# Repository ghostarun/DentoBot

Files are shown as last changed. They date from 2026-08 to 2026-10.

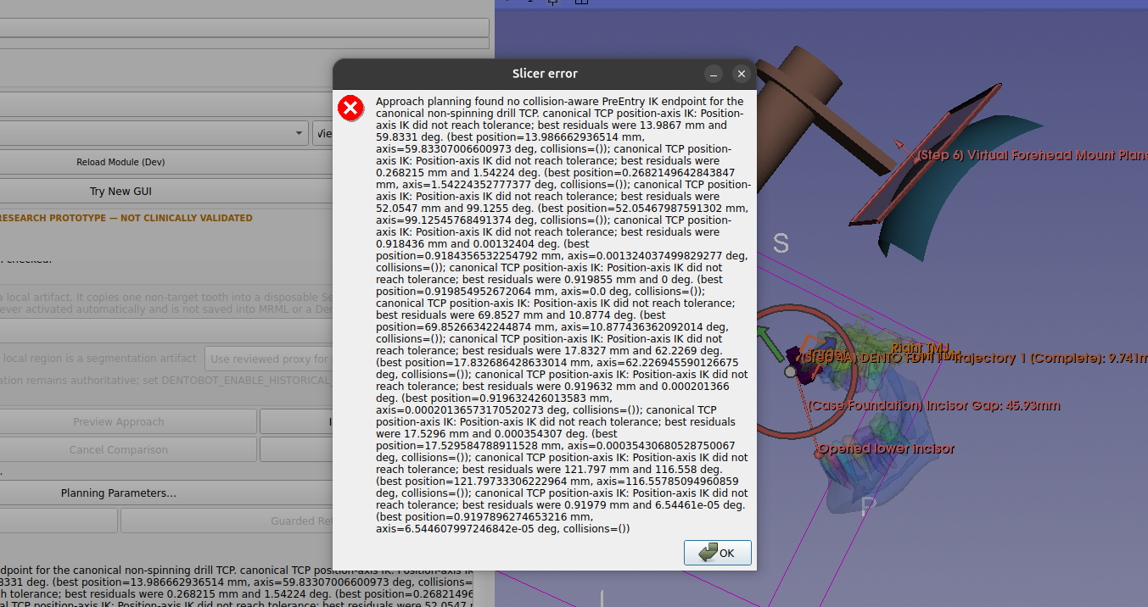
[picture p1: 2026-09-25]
Workspace/docs/diagnostics/evidence/fdi11-step6-2026-09-24/07-later-ik-error-repeat.png

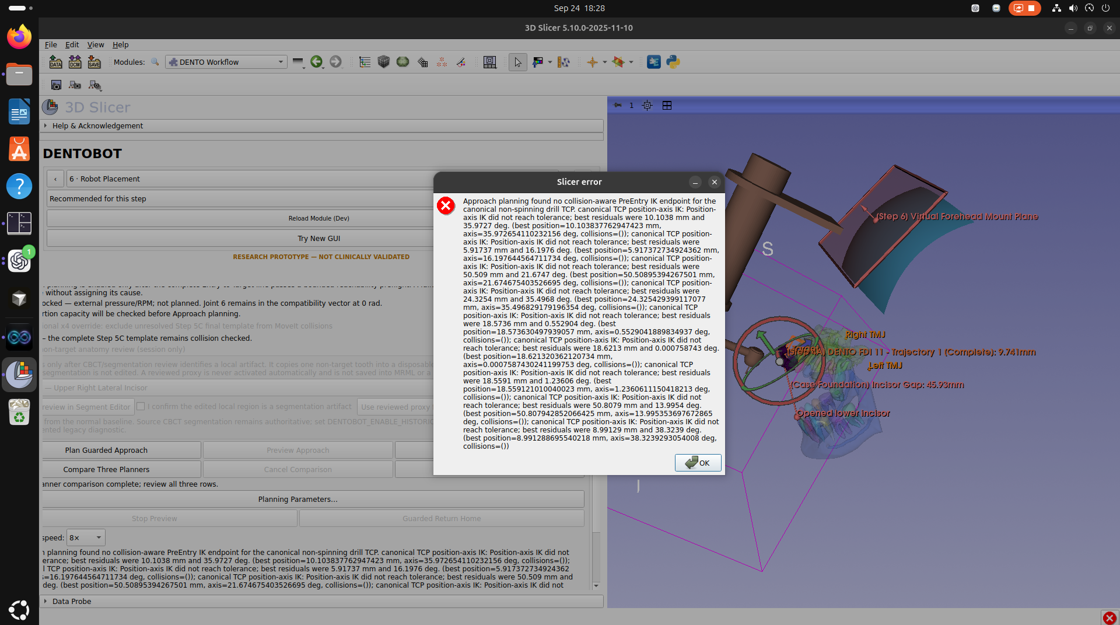
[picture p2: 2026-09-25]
Workspace/docs/diagnostics/evidence/fdi11-step6-2026-09-24/03-earlier-ik-error.png

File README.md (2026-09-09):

# DENTOBOT

DENTOBOT is an academic research prototype for a focused dental
image-guidance workflow built on 3D Slicer. It is not validated clinical
software and does not authorize drilling or patient treatment.

## Alternating development between machines

Use `main` as the shared development baseline and work on only one machine at
a time. Before switching devices, commit the intended source/documentation
changes and push the active branch. On the next device, inspect `git status`,
fetch origin, and use `git pull --ff-only` on that same branch before editing.
If Git reports local changes or divergent history, preserve that work and
reconcile it before continuing; do not reset or force-push to synchronize.
Uncommitted files and local-only commits do not travel between machines.

Keep `.dentobot.env`, `compose.override.yaml`, datasets, model caches, Conda
environments, and build/install trees local to each device. Record the active
branch, commit, outstanding work, and verification limits in the dated logbook
at handoff. Each machine retains its own CPU/CUDA and graphics configuration.

The Ubuntu NVIDIA and Windows WSLg/CUDA setup paths are integrated in `main`.
Each remains tied to its documented host profile and recorded verification;
installation on a new machine still ends with the profile's check-only gate.

## Supported runtime profiles

DENTOWorkflow uses the same MRML, planning, and geometry code on Windows and
Linux. Only the external-process and deployment adapters differ:

| Host profile | Slicer process | Inference process | Docker | SlicerROS2 |
|---|---|---|---|---|
| Windows 11 + WSLg (primary) | Linux Slicer 5.10 in `dentobot-slicerros2` through WSLg | Direct Linux Python in WSL (`cpu` or `cuda:0`) | Required | Included; Steps 0–6 simulation |
| Native Windows fallback | Native Windows Slicer | WSL2 Linux (`wsl.exe`) | Not required | Unavailable; Steps 0–5 only |
| Ubuntu (CPU) | Linux Slicer in the pinned SlicerROS2 container | Direct external Linux Python (`cpu`) | Required | Included |
| Ubuntu + NVIDIA | Same container | Direct external Linux Python (`cuda:0`) | Required + NVIDIA Container Toolkit | Included |

The inference stack is never installed into Slicer's embedded Python. Both
profiles launch the exact external Linux interpreter, exchange NIfTI plus
JSON in isolated run folders, and pass the device explicitly.

### Windows 11 + WSLg: primary full workflow and Step 6 simulation

Use this profile when Windows must run the same Linux SlicerROS2 simulation
stack as Ubuntu. It requires Windows 11 with WSLg, a WSL Ubuntu distribution,
and exactly one Docker daemon: Docker Engine inside that distribution by
default, or Docker Desktop with WSL integration as an alternative. Do not run
both daemon paths together. NVIDIA container support is required when using
`cuda:0`. WSLg is accepted for functional GUI checks, not rendering performance
acceptance. See [Workspace/docs/WINDOWS_SETUP.md](Workspace/docs/WINDOWS_SETUP.md)
for both host bootstraps. Lab users install immutable dated tags; `main` is not
a lab release.

```powershell
# Use the exact name printed by: wsl -l -v
$env:DENTOBOT_WSL_DISTRIBUTION = "Ubuntu"

# From a clone checked out at the intended lab tag or integration revision:
Workspace\scripts\install-lab-wsl.bat

# Cache TotalSegmentator tasks 298, 115, and 113. Safe to rerun.
Workspace\scripts\install-lab-model-cache.bat

# Launch Linux SlicerROS2 through WSLg.
Workspace\scripts\launch-lab-workflow.bat
```

The installer creates the WSL overlay and pins the SlicerROS2 dependency. Set
`DENTOBOT_GRAPHICS_MODE=wslg` in `~/dentobot/.dentobot.env`; select `cpu` with
the Python 3.12 CPU environment or `cuda:0` with the Python 3.10 cu130
environment. The launcher merges the tracked WSLg and CUDA Compose overlays,
builds the three required ROS packages in the bind-mounted workspace, checks
the selected inference device, and fails before GUI launch when prerequisites
are missing. See `Workspace/docs/SETUP.md` for GHCR authentication, environment
creation, first-install recovery, and exact verification commands.

### Legacy fallback: native Windows Slicer, Steps 0–5 only

This is a limited compatibility workaround. It deliberately hides Step 6,
does not load SlicerROS2, and must not be used when the full Windows
installation is intended. Native Windows Slicer plus native Windows ROS is
outside the current project scope.

Copy and edit the machine-local example, then launch native Windows Slicer:

```powershell
Copy-Item Workspace\.dentobot.windows.env.example .dentobot.windows.env
powershell -ExecutionPolicy Bypass -File `
  Workspace\scripts\launch-native-windows-steps0-5.ps1 -CheckOnly
powershell -ExecutionPolicy Bypass -File `
  Workspace\scripts\launch-native-windows-steps0-5.ps1
```

The Windows launcher validates Slicer, the named WSL distribution, the exact
Linux backend interpreter, the requested CPU/CUDA device, and a local Windows
run-record directory before opening DENTO Workflow. Docker Desktop is not
needed for Steps 0–5 segmentation, planning, template generation,
verification, or STL export. The launcher sets an explicit workflow profile
that removes Step 6 and disables its saved-checkpoint runtime restoration.

Current upstream SlicerROS2 1.2 compatibility targets Ubuntu 24.04, ROS 2
Jazzy, and source-built Slicer 5.10/5.12. A native Windows SlicerROS2 build is
not an upstream tested target. Robot/ROS-integrated Windows work uses the
primary Windows WSLg profile above. Native Windows Slicer remains the
Steps 0–5 fallback only.

Official references: [SlicerROS2 compatibility](https://slicer-ros2.readthedocs.io/en/devel/pages/compatibility.html),
[SlicerROS2 getting started](https://slicer-ros2.readthedocs.io/en/devel/pages/getting-started.html), and
[SlicerROS2 CI image](https://slicer-ros2.readthedocs.io/en/devel/pages/ci-docker-image.html).

## Ubuntu workspace orchestration

The repository lives at `ros2_ws/src/DentoBot` under an overlay root such as
`~/dentobot`. Tracked `Workspace/` owns the Ubuntu launcher, Compose
definition, helper scripts, active workspace notes, and top-level agent
instructions. The overlay preserves `scripts`, `docs`, `tools`,
`compose.yaml`, and `AGENTS.md` as relative symlinks. See
`Workspace/HOST_LAYOUT.md` for the overlay map.

Create the compatibility links safely in a new workspace with:

```bash
mkdir -p ~/dentobot/ros2_ws/src
git clone https://github.com/ghostarun/DentoBot.git ~/dentobot/ros2_ws/src/DentoBot
# Pin slicer_ros2_module to Workspace/LAB_RELEASE (required for Slicer launch)
git clone https://github.com/ghostarun/slicer_ros2_module.git \
  ~/dentobot/ros2_ws/src/slicer_ros2_module
git -C ~/dentobot/ros2_ws/src/slicer_ros2_module checkout \
  "$(awk -F= '/^SLICERROS2_SHA=/{print $2}' \
    ~/dentobot/ros2_ws/src/DentoBot/Workspace/LAB_RELEASE)"
bash ~/dentobot/ros2_ws/src/DentoBot/Workspace/bootstrap-workspace.bash
```

Copy `Workspace/.dentobot.env.example` to the workspace root as
`.dentobot.env` and edit only that untracked file for the local Conda
interpreter, device (`cpu` or `cuda:0`), and graphics render node. DENTO
Workflow receives those values from the launcher automatically; no machine
path needs to be remembered or saved in an MRB scene.

From the surrounding workspace, Git can be addressed without remembering the
nested checkout path:

```bash
scripts/git-dentobot.bash status --short --branch
```

### Ubuntu first-run checklist

1. Install Docker Engine. For NVIDIA hosts also install the NVIDIA Container
   Toolkit (`Workspace/scripts/install-host-nvidia-docker.bash` or equivalent)
   and reboot if the kernel module and userspace driver versions disagree.
2. Create the Conda `dentobot` environment from `Inference/` using either the
   Ubuntu CPU manifests or the Bridge C CUDA pins
   (`environment.yml` + `requirements/pytorch-cu130.txt` +
   `requirements/runtime-validated.txt`). Install CUDA torch **and**
   torchvision from the same `cu130` index (`torchvision==0.25.0+cu130`); a
   generic torchvision wheel breaks TotalSegmentator with
   `operator torchvision::nms does not exist`. Install packages into the env
   with `PYTHONNOUSERSITE=1` so nothing lands only under `~/.local` (user-site
   is not bind-mounted into the container).
3. Cache TotalSegmentator tasks **113**, **115**, and **298** under
   `data/model-cache/totalsegmentator`. Prefer calling
   `totalsegmentator.libs.download_pretrained_weights` for task IDs 115 and
   113; the CLI `-t` choices do not currently expose `teeth` /
   `craniofacial_structures` by name. Task 298 arrives with `total` /
   `total_fast`.
4. Build or pull the Compose image
   `dentobot/slicerros2:jazzy-moveit-sim-20260909` (see
   `Workspace/Dockerfile.slicerros2` / `Workspace/LAB_RELEASE`).
5. On NVIDIA hosts, the launcher automatically merges the tracked
   `Workspace/compose.cuda.yaml` when `DENTOBOT_BACKEND_DEVICE=cuda:0`.
   Reserve an untracked `compose.override.yaml` for machine-specific changes.
6. The launcher builds `dentobot_description`, `dentobot_moveit_config`, and
   `slicer_ros2_module` inside the container. A missing
   `slicer_ros2_module` install produces
   `package 'slicer_ros2_module' not found` at GUI launch.

```bash
cd ~/dentobot
./scripts/launch-dentoworkflow.bash --check-only
./scripts/launch-dentoworkflow.bash
```

Long-form workstation notes remain in `Workspace/docs/SETUP.md`.

## Ubuntu + NVIDIA (CUDA inference)

Verified on Ubuntu 22.04 with an AMD iGPU + NVIDIA RTX 4060 Laptop (driver
580.x, CUDA 13.0 wheels). Split responsibilities deliberately:

- **Slicer OpenGL:** Mesa DRM render node (AMD/Intel), set
  `DENTOBOT_RENDER_DEVICE` to the matching `/dev/dri/renderD*`.
- **Segmentation CUDA:** host Conda Python with `torch==2.10.0+cu130`,
  `DENTOBOT_BACKEND_DEVICE=cuda:0`, NVIDIA devices injected into the container
  through Container Toolkit and the tracked CUDA Compose overlay.

Example overlay `.dentobot.env` fragment:

```bash
DENTOBOT_BACKEND_PYTHON=/absolute/path/to/conda/envs/dentobot/bin/python
DENTOBOT_BACKEND_EXECUTION_MODE=local
DENTOBOT_BACKEND_DEVICE=cuda:0
DENTOBOT_RENDER_DEVICE=/dev/dri/renderD128   # Mesa node, not nvidia
```

Confirm before GUI launch:

```bash
nvidia-smi
docker run --rm --gpus all nvidia/cuda:12.6.0-base-ubuntu22.04 nvidia-smi
"$DENTOBOT_BACKEND_PYTHON" -m dentobot_inference health --json --require-device cuda:0
./scripts/launch-dentoworkflow.bash --check-only
```

Reject `llvmpipe` / `swrast` for interactive OpenGL acceptance unless software
rendering is deliberate. A driver/library version mismatch
(`NVML` vs loaded kernel module) requires reboot after cleaning duplicate
driver packages.

## ROS 2 robot description

The tracked `dentobot_description` package is exposed to colcon through the
workspace bootstrap's `ros2_ws/src/dentobot_description` relative symlink.
Build and run the simulation-only neutral description inside the Jazzy
container:

```bash
docker exec dentobot-slicerros2 bash -lc \
  'source /opt/ros/jazzy/setup.bash &&
   cd /workspace/ros2_ws &&
   colcon build --symlink-install --packages-select dentobot_description'

docker exec -it dentobot-slicerros2 bash -lc \
  'source /opt/ros/jazzy/setup.bash &&
   source /workspace/ros2_ws/install/setup.bash &&
   ros2 launch dentobot_description description.launch.py use_rviz:=false'
```

The launch publishes neutral joint states and TF for inspection only. It has
no controller, command topic, hardware plugin, or motion path. See
`dentobot_description/README.md` for provenance and unresolved calibration,
collision, frame, and physical-verification work.

DENTOWorkflow also exposes **6 · Robot Placement** for scene-only
placement. It loads the same tracked URDF/STLs into an MRML transform hierarchy,
allows manual joint changes, and provides an editable mount plane with explicit
snap plus local button/keyboard nudges. This is not a live ROS/SlicerROS2 bridge:
it reads no robot state, sends no command, and does not establish head-mount
registration, a calibrated TCP, collision safety, or hardware readiness.

For the current disposable workspace check, Step 6 can load local aligned
BodyParts3D skull/maxilla/mandible meshes, collect approximate left/right TMJ
and upper/lower central-incisor landmarks, and rotate the mandible about the
TMJ axis to an approximately 40 mm final incisor gap. The robot base can then
be dragged/snapped to a provisional forehead plane, fine-tuned by buttons or
opt-in keyboard controls, and articulated with the six manual joint controls.
See `Workspace/docs/SETUP.md` for asset checksums and the exact trial sequence.
This is generic design visualization only, not clinical jaw simulation,
registration, collision validation, or robot control.

## Ubuntu interactive rendering

A visible Slicer window does not prove hardware acceleration. On Ubuntu,
containerized Slicer needs a working host GPU driver, a compatible userspace
OpenGL driver in the image, and explicit access to the intended DRM render
node.

Inspect the host first:

```bash
lspci -nnk | grep -A4 -Ei 'vga|3d|display'
ls -l /dev/dri
readlink -f /sys/class/drm/renderD128/device/driver
readlink -f /sys/class/drm/renderD129/device/driver
```

For Mesa-backed Intel and AMD graphics, map the actual non-modesetting render
node into the service (Compose already takes `DENTOBOT_RENDER_DEVICE`):

```yaml
services:
  slicerros2:
    devices:
      - /dev/dri/renderD128:/dev/dri/renderD128
```

The node number may differ on multi-GPU systems. Non-root container users also
need the matching host render-group GID. AMD requires a compatible Mesa
`radeonsi` driver. Proprietary NVIDIA CUDA for the *inference* process uses
NVIDIA Container Toolkit and `Workspace/compose.cuda.yaml`; do not copy the
Intel/AMD DRM recipe blindly as a substitute for `/dev/nvidia*`.

Slicer 5.10 may lower the entire Linux process priority when initializing its
background threads. Preserve interactive priority with:

```yaml
services:
  slicerros2:
    environment:
      SLICER_BACKGROUND_THREAD_PRIORITY: "0"
```

Save and close Slicer before recreating a container. Then verify both device
access and renderer identity; reject `llvmpipe` or `swrast` unless software
rendering is deliberately requested.

### Verified workstation notes

- **IITM CPU/Intel profile:** Intel Arrow Lake-S (`i915`),
  `/dev/dri/renderD128`, Mesa Intel OpenGL 4.6, Slicer nice 0,
  `DENTOBOT_BACKEND_DEVICE=cpu`. Full procedure: `Workspace/docs/SETUP.md`.
- **NVIDIA dual-GPU profile (2026-09-07):** Ubuntu 22.04, AMD Mesa render node
  for Slicer + NVIDIA RTX 4060 for `cuda:0` inference; launcher
  `--check-only` passed with CUDA health inside the container. See logbook
  `2026-09-07` and task `PLAT-U-05`.

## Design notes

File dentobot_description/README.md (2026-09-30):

# DENTOBOT ROS 2 description

This package is the first simulation-only integration of the supplied CAD
export. It publishes the URDF through `robot_state_publisher` and supplies
neutral, manual, and Slicer joint-state modes so the complete tree can be
inspected and articulated without a controller or robot connection.

## Source and normalization

The source bundle was received under the workspace-local
`data/ROS/assembly` directory on 2026-08-14. Its unmodified URDF SHA-256 is
`e04d644a85eaeb518507cbe991e2007e1f0194c7cc4b834fc608d9d6b1beda45`.
The seven copied binary STL checksums are enforced by the package test.

The initial integration made three URDF normalizations:

- the robot name changed from the generic `assembly` to `dentobot`;
- relative mesh paths changed to
  `package://dentobot_description/meshes/...`;
- a massless `base_link` and fixed joint were placed above `link-1`
  because KDL does not retain inertia on a URDF root link.

On 2026-08-14 the developer selected a photographed design pose as the new
draft zero configuration. The old manual arm values absorbed into the URDF
joint origins are J1 `25.38 deg`, J2 `0 mm`, J3 `62.46 deg`, J4 `0 mm`, and J5
`1.08 deg`; the finite revolute limits were shifted by the same offsets so
their original 360-degree spans remain available around the new zero. The
fixed spindle-housing-to-burr transform preserves the photographed tool
assembly pose. The fixed root rotates link-1 by -90 degrees about X, placing
its thin Y-normal mounting face on the RViz XY plane with the articulated chain
above the grid. J4's axis is negated while retaining its positive `0–75 mm`
control range, so increasing J4 now moves primarily in negative `base_link` X.

On 2026-09-01 J2 was normalized so its mechanically extended/home end is
`0 mm`. The former description used that same physical pose at `80 mm`.
The tracked URDF moves the J2 joint origin to the former `q=0.08 m` pose and
reverses its axis, so physical geometry is preserved by
`q_new = 0.08 m - q_old`. DENTOWorkflow applies this exact conversion only to
packages carrying the fingerprint of the tracked former URDF; saved Task Home
runtime evidence and workspace samples are then required to be regenerated.
The J1/J3/J5 photographed-pose offsets above remain absorbed into their URDF
origins, so their configured default Home values remain displayed as zero.

The same simulation-profile revision declares J5 continuous. The former
finite interval `-1.08–358.92 deg` covered one full revolution but forced a
pose just below zero to be represented as an almost-complete positive turn.
MoveIt and DENTOWorkflow now use the shortest representation relative to the
accepted start state for J5. Pneumatic turbine rotation is outside the
positioning model; the spindle housing and burr remain in the URDF as rigid
geometry.

The received source URDF remains unchanged under `data/ROS/assembly`. Mesh
bytes, link frames/geometries, masses, inertias, and the other joint axes are
unchanged in the tracked description.

## Build and inspect

From the DENTOBOT Jazzy container workspace:

```bash
source /opt/ros/jazzy/setup.bash
cd /workspace/ros2_ws
colcon build --symlink-install --packages-select dentobot_description
source install/setup.bash
ros2 launch dentobot_description description.launch.py
```

For a headless transport/TF check, omit RViz:

```bash
ros2 launch dentobot_description description.launch.py use_rviz:=false
```

## Manual joint articulation

From an Ubuntu graphical desktop terminal, use the workspace launcher:

```bash
cd /home/light-tarun/dentobot
./scripts/launch-dentobot-manual-rviz.bash
```

The launcher verifies the reusable container, rebuilds only this small
description package, refuses a duplicate description launch, grants temporary
X11 access, and opens RViz beside the package-owned manual slider window.

The five controls follow URDF order. Revolute values are displayed in degrees;
prismatic values are displayed in millimetres. Published
`sensor_msgs/msg/JointState` positions remain in ROS SI units (radians and
metres):

| Joint | Type | Manual display range |
| --- | --- | --- |
| `link-1_Revolute-1` | revolute | -25.38–334.62 deg |
| `link-2_Slider-2` | prismatic | 0 mm extended/home–80 mm retracted |
| `link-3_Revolute-3` | revolute | -62.46–297.54 deg |
| `link-4_Slider-4` | prismatic | 0–75 mm |
| `link-5_Revolute-5` | continuous | -180–180 deg display window |

All five displayed values start at zero. **Reset all joints to zero** restores
the photographed pose, not the original CAD-export pose.

The direct ROS equivalent is:

```bash
ros2 launch dentobot_description manual.launch.py
```

### Draft 5 mm link-box clearance

Manual mode computes a base-frame axis-aligned bounding box (AABB) around each
transformed collision mesh. It compares every non-adjacent link pair and warns
when the Euclidean distance between their boxes is below 5 mm. Direct
parent-child pairs are ignored because connected joint geometry is expected to
touch or overlap. The manual window lists the closest warning pairs and shows
the current `burr` link origin in `base_link` millimetres. RViz subscribes to
`/dentobot/coarse_self_collision_boxes`; green outlines are clear and red
outlines participate in a warning.

This is intentionally conservative draft logic. Rotated axis-aligned boxes can
overlap even when the actual triangles do not, and the current collision meshes
are the unreduced visual STLs. At neutral, the draft checker reports
`link-3`/`link-5` and `link-3`/`pneumatic_spindle-Copy` AABB overlap. Do not
interpret those warnings as confirmed physical collision, and do not interpret
a clear result as continuous-path or patient/head clearance. The `burr` origin
is a CAD link origin, not a calibrated tool centre point.

The default can be made more conservative for an experiment, for example:

```bash
ros2 launch dentobot_description manual.launch.py coarse_clearance_mm:=10.0
```

`description.launch.py` also accepts `joint_state_mode:=neutral` (the default),
`joint_state_mode:=manual`, `joint_state_mode:=slicer`, or
`joint_state_mode:=external`. Slicer mode starts
`dentobot_slicer_joint_state_publisher`, which republishes Motion Control
slider commands from `dentobot/slicer_joint_positions` as `/joint_states`.
External mode starts no joint-state source and exists for bounded TF tests or a
future simulator. Do not run more than one joint-state publisher for the model.

Package-owned publishers write `sensor_msgs/msg/JointState` for visualization.
The Slicer path also listens to `std_msgs/msg/Float64MultiArray` commands. None
of these interfaces expose controllers, transmissions, `ros2_control`, a
hardware plugin, or any robot motion path.

## Evidence boundary and open engineering work

Passing the package tests or displaying the model establishes only static and
synthetic description integrity. Before this model can support kinematics,
collision planning, calibration, or hardware integration, the team must verify:

- physical joint zero definitions, positive directions, usable ranges,
  velocity limits, effort limits, and units;
- link/joint naming and the intended `base_link`, end-effector, spindle, TCP,
  bur-tip, and docking frames;
- masses, centers of mass, and inertia tensors against the physical assembly;
- visual mesh alignment and scale against measured dimensions;
- simplified, conservative collision geometry instead of reusing every visual
  mesh verbatim;
- self-collision pairs, transmissions/actuators, controller interfaces, and
the robot-control/safety boundary;
- the explicit transform chain from Slicer RAS through the physical docking
  and robot frames.

No powered motion, drilling, patient use, or safety claim is authorized by
this package.

## Step 6 planning frame

MoveIt group `dentobot_arm` plans exactly J1–J5 to the fixed
`dentobot_drill_tcp` frame. The TCP keeps its existing burr-tip reference
transform and physical +Z drilling axis. The spindle housing, burr, and older
`dentobot_tool_tcp` and `dentobot_drill_tip_provisional` frames remain in the
description at fixed physical transforms for visualization and collision
checking. Task Home, IK, workspace samples, trajectories, phase-guard
commands, and previews use exactly five SI joint values.

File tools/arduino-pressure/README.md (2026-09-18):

# Arduino pressure monitor

Host sensing bench for the DENTOBOT pneumatic pressure setup: live serial
plot, stage cues, CSV recording, and post-run inspection.

Tracked path: `tools/arduino-pressure/` inside the DentoBot git checkout.
The Ubuntu overlay exposes it as `~/dentobot/tools/arduino-pressure` via
the same symlink pattern as `docs/` and `scripts/`.

Sensing only. It does not command a robot, authorize drilling, or implement
a safety stop. Do not install these packages into Slicer, Conda `dentobot`,
or the SlicerROS2 container.

## Layout

```text
tools/arduino-pressure/
  pressure_monitor.py       live GUI
  pressure_analysis.py      post-processing GUI / --no-gui
  pressure_config.py        filter / sample-rate panel
  pressure_filter.py
  pressure_signal.py
  pressure_plot.py
  pressure_annotate.py
  pressure_cli.py           --port / --wifi / --list-ports
  pressure_transport.py     serial vs WiFi TCP link
  pressure_bridge.py        USB→TCP when campus WiFi is LDAP/enterprise
  firmware/pressure_monitor/pressure_monitor.ino   Arduino sketch (firmware)
  firmware/pressure_monitor/arduino_secrets.h.example
  requirements.txt
  pressure_runs/            local CSVs (gitignored except .gitkeep)
```

## Setup (Ubuntu)

```bash
sudo apt update
sudo apt install python3 python3-venv python3-pip libxcb-cursor0 libxcb-xinerama0
cd tools/arduino-pressure
python3 -m venv .venv
source .venv/bin/activate
python -m pip install --upgrade pip
python -m pip install -r requirements.txt
sudo usermod -aG dialout "$USER"   # then log out and back in
```

On this workstation the existing interpreter is
`/home/light-tarun/pressure-env/bin/python`.

## Setup (Windows)

1. Install Python 3.10+ with **Add python.exe to PATH**.
2. In this folder:

```bat
python -m venv .venv
.venv\Scripts\activate
python -m pip install --upgrade pip
python -m pip install -r requirements.txt
```

## Firmware (Arduino sketch)

In Arduino IDE 2.x this file is a **sketch** (not a “script”):
`firmware/pressure_monitor/pressure_monitor.ino`. Target board: **Arduino UNO
R4 WiFi** (plain UNO has no WiFi).

1. Copy `firmware/pressure_monitor/arduino_secrets.h.example` to
   `arduino_secrets.h` in the same folder.
2. **IITM `iitmwifi` (802.1X PEAP / LDAP):** the board **cannot** join the same
   network your laptop uses for campus login. Set `PRESSURE_WIFI_MODE` to **`2`**
   so the Arduino **hosts** a small WPA2 access point (`AP_SSID` / `AP_PASS`).
   On the PC, connect WiFi to that AP (you can keep **Ethernet** on `iitmwifi`
   for internet). Then:
   `python pressure_monitor.py --wifi --wifi-host 192.168.4.1` (confirm IP on
   Serial Monitor once after flash).
3. **Other WPA2-PSK WiFi (phone hotspot, lab router):** `PRESSURE_WIFI_MODE`
   **`1`**, set `SECRET_SSID` / `SECRET_PASS`, flash, read `# WIFI IP …` on
   Serial Monitor at 460800 baud.
4. **WiFi off:** `PRESSURE_WIFI_MODE` **`0`** — USB only, or USB +
   `pressure_bridge.py` if the PC is on campus WiFi and you want TCP.
5. USB line format: `seq,micros,raw_adc`. Host command: `RATE <hz>` (200–1500).
   The same lines work over **TCP** (board WiFi or host bridge).

### Campus network: USB + bridge (recommended)

Your laptop joins campus WiFi with LDAP as usual. The Arduino stays on USB.

```bash
# Terminal 1 — on the laptop that owns the USB cable
python pressure_bridge.py --port /dev/ttyACM0 --listen 0.0.0.0:8765

# Terminal 2 — same laptop or another PC on the same campus LAN
python pressure_monitor.py --wifi --wifi-host <laptop-ip>
```

Use the laptop’s campus IP (`ip a` / `hostname -I`). Firewall rules on the
laptop must allow inbound TCP 8765 from your bench PC if you split terminals
across machines. Same-machine use: `--wifi-host 127.0.0.1`.

Ask campus IT for a **device PSK SSID** only if you need the board on WiFi
without a bridge; LDAP credentials still cannot be stored in the sketch.

## Run

`pressure_monitor.py` sets **`USE_WIFI_BY_DEFAULT = True`** and
**`DEFAULT_WIFI_HOST = 192.168.4.1`** at the top of the file (same on Linux and
Windows). With the PC WiFi joined to the board AP, run with **no arguments**:

```bash
python pressure_monitor.py
```

Set `USE_WIFI_BY_DEFAULT = False` there to fall back to USB serial.

**Linux**

```bash
python pressure_monitor.py --list-ports
python pressure_monitor.py --port /dev/ttyACM0   # USB if WiFi default off
python pressure_monitor.py --wifi --wifi-host 192.168.4.1
./run_monitor.sh
./run_monitor_wifi.sh
```

**Windows** (venv activated or `run_monitor.bat`)

```bat
python pressure_monitor.py
python pressure_monitor.py --list-ports
python pressure_monitor.py --port COM5
python pressure_monitor.py --wifi --wifi-host 192.168.4.1
run_monitor.bat
run_monitor_wifi.bat
set PRESSURE_WIFI_HOST=192.168.4.1
```

Allow **Python** through Windows Firewall if the GUI connects but gets no data.
`pressure_analysis.py` / `pressure_analysis.py --no-gui` work the same on both OSes.

Helpers: `run_monitor.sh` / `run_monitor.bat`, `run_monitor_wifi.sh` /
`run_monitor_wifi.bat`, and the analysis equivalents.

Recordings land in `pressure_runs/run_<timestamp>/`. Those folders are not
committed.

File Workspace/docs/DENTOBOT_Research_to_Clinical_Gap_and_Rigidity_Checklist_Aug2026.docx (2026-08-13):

DENTOBOT
Research-to-Clinical Gap Closure & Engineering Rigidity Checklist

Fast-track PoC decision document | IITM Dental Drilling Robot | August 2026

Purpose: convert the current software/geometry progress into a finite set of research questions, acceptance checks, and parallel project lanes. This is not a product-grade specification. It is a PoC closure document: answer enough of each question to make the TRL-4 prototype defensible, measurable, and ready to connect to registration and robotics.

# How to use this document

Use Section 1 with the dental/clinical team. Use Section 2 as the engineering rigidity checklist before calling a subsystem 'done enough'. Use Sections 3-5 to prevent DENTOBOT imaging/template work from hiding the tooth-mounted robot, registration, sensing, and robot-execution lanes.

Decision rule: every requirement should eventually become one of three things - a numeric acceptance threshold, a bounded qualitative acceptance test, or an explicitly deferred question with a reason.

# 1. Research → Clinical Requirement Closure Questions

## 1.1 Procedure and clinical use-case boundary

☐ What exact portion of root-canal treatment is this PoC intended to automate: access trajectory planning, access cavity drilling, chamber entry, or a narrower bounded drilling task?

☐ What is explicitly outside the autonomous scope for TRL-4?

☐ What is the clinician expected to approve before robot motion begins?

☐ What events require the clinician to stop, re-plan, re-register, or abandon autonomous execution?

☐ What is the expected patient/phantom positioning and what motion is permitted during the procedure?

☐ What is the intended failure-safe state if software, registration, sensing, or robot motion becomes uncertain?

## 1.2 Anatomy, segmentation and imaging

☐ Which anatomical structures must be segmented reliably for planning: whole tooth, crown, roots, pulp chamber/canals, neighboring teeth, bone, gingiva surrogate?

☐ What segmentation errors materially affect trajectory or template seating, and which errors are visually tolerable but clinically irrelevant?

☐ What is the minimum CBCT resolution/FOV/quality assumed by the PoC?

☐ How will metal artifacts, restorations, crowns, missing teeth, partial scans, and noisy boundaries be handled or excluded?

☐ What constitutes sufficient human review of the AI segmentation before planning?

☐ Do corrected masks require quantitative recomputation before downstream use, or is explicit provenance enough for PoC?

## 1.3 Entry, target and trajectory semantics

☐ What anatomical definition is used for Entry?

☐ What anatomical definition is used for Target/end point?

☐ What structures define a hard no-go region?

☐ What minimum remaining dentin/enamel safety margin is required around the planned path?

☐ What maximum angular and translational planning error is acceptable for the PoC?

☐ Should the trajectory be straight-line only for the PoC, and what drill/bur diameter/depth assumptions constrain it?

☐ What does the dentist need to see in oblique MPR to approve or correct a trajectory?

☐ What is the acceptance criterion for assisted/automatic trajectory suggestions versus manually corrected trajectories?

## 1.4 Tooth-supported template / shell

☐ Which surfaces are intended to provide support and retention: occlusal, buccal, lingual/palatal, proximal, or a controlled combination?

☐ What surfaces must be excluded because of gingiva/soft tissue, poor segmentation, restoration, or access difficulty?

☐ What insertion direction should the guide use, and can one direction serve all selected support teeth?

☐ How much undercut engagement is useful for retention and how much prevents seating/removal?

☐ What clearance should exist between tooth surface and printed shell for the chosen printer/material/process?

☐ What minimum wall thickness is needed to avoid clinically meaningful flexure during docking/drilling?

☐ What crown coverage is required for stable seating, and should coverage be geometry-driven rather than a fixed percentage?

☐ How many support teeth are required for the intended target and load case?

☐ What visual/tactile evidence makes the dentist accept or reject guide seating?

☐ How many repeated insert/remove cycles should preserve repeatable seating for the PoC?

☐ What is the acceptable rocking/gap at full seating?

☐ What gingival/cervical margin rule is acceptable for the PoC?

☐ What is the manufacturing/export validation required before a shell is considered testable?

## 1.5 Sleeve, channel and drilling interface

☐ What is the actual bur/drill outer diameter and what radial clearance is required?

☐ Is a physical sleeve required, or is the template primarily a robot docking reference?

☐ What sleeve/channel height is sufficient to constrain the tool without causing access or collision problems?

☐ What maximum axis misalignment between planned trajectory and fabricated channel is acceptable?

☐ What drill-depth stop or software depth reference is used?

☐ How is heat/debris/irrigation access affected by the guide?

☐ Does the guide need to resist direct drill reaction loads, robot docking loads, or both?

## 1.6 Registration and coordinate-chain requirements

☐ What is the authoritative patient/tooth coordinate frame?

☐ Where is the template coordinate frame physically realized?

☐ How is the robot base/end-effector frame registered to the template/tooth frame?

☐ Which transform chain is used to convert planned RAS trajectory coordinates into robot motion coordinates?

☐ Which transforms are measured once, which are calibrated, and which must be re-estimated after every mounting?

☐ What event invalidates registration: patient movement, guide removal, robot redocking, tool change, template deformation?

☐ What target registration error (TRE) at the tooth/drilling target is acceptable?

☐ How will registration error be measured independently from robot positioning error?

☐ Can the robot be removed and re-docked while preserving registration within the PoC tolerance?

## 1.7 Safety and clinical control

☐ What is the maximum allowed drilling depth and how is it independently limited?

☐ What hard geometric constraints prevent motion outside the approved corridor?

☐ What sensor/feedback condition should trigger immediate stop?

☐ What latency is acceptable between detected abnormal condition and drill stop?

☐ What happens if registration confidence degrades after approval?

☐ What physical emergency stop / software stop / clinician override is required for the prototype?

☐ What states require a fresh confirmation rather than continuing automatically?

# 2. Engineering Rigidity Checklist - 'Done Enough' Gates

This section is deliberately stricter than 'it worked once'. A PoC does not need product-grade robustness, but every critical assumption should survive a repeatable bounded test.

## 2.1 Data and geometry integrity

☐ Same CBCT produces the same physical geometry after save/reopen.

☐ Voxel spacing, origin, orientation/affine, and transforms are preserved across every external-process boundary.

☐ Segmentation aligns with source CBCT after inference/import and after MRB reopen.

☐ No logic relies on editable MRML node names for identity.

☐ Wrong-role nodes (e.g., Step 4A ROI used as Step 5B ROI) are rejected.

☐ Derived outputs identify their authoritative parents and Current/Stale state.

## 2.2 Segmentation / review robustness

☐ Representative CBCT loads and segmentation completes on the intended development runtime.

☐ Failure paths for missing model/dependency/device produce actionable errors rather than corrupted scene state.

☐ Human correction invalidates/relabels baseline metrics appropriately.

☐ Reviewed state survives scene save/reopen.

☐ Planning cannot silently proceed on the wrong segmentation/source pair.

## 2.3 Trajectory planning robustness

☐ Entry/Target invariant remains exactly 0-2 points; >2 cannot occur.

☐ Trajectory length/direction are calculated in world millimetres.

☐ Oblique MPR remains trajectory-aligned during correction and selection changes.

☐ Multiple trajectories remain correctly associated with their target teeth.

☐ Scene reopen restores target, trajectory, bounds, highlights and associations.

☐ Editing/deleting a trajectory cannot silently leave valid-looking but mismatched descendants.

## 2.4 Template geometry robustness

☐ Support selection produces one deterministic owned support-anatomy model.

☐ Automatic visible/crown support boundary is connected and editable.

☐ Insertion direction is explicit and persisted.

☐ Undercut handling does not produce a guide that cannot be inserted on representative anatomy.

☐ Clearance and wall thickness are explicit parameters with recorded values.

☐ Shell is watertight/manifold before export.

☐ Shell contains no obvious disconnected islands, self-intersections or unintended internal fragments.

☐ Trajectory/sleeve/docking geometry remains correctly aligned after shell regeneration.

☐ Finalized shell remains distinct from raw source shell and stale finalizations cannot export.

☐ STL reopens with expected scale, orientation and topology.

## 2.5 Physical template checks

☐ Print at least one representative guide with recorded material/process settings.

☐ Guide reaches intended terminal seating without excessive force.

☐ No visible rocking under light manual load.

☐ Repeated seating produces similar final pose.

☐ Guide can be removed without fracture or unacceptable locking.

☐ Shell does not visibly flex under expected docking/drilling load.

☐ Sleeve/docking feature remains rigid relative to tooth-supported body.

☐ Measure physical-versus-planned critical dimensions after printing.

## 2.6 Registration / metrology rigidity

☐ Every transform in the chain is explicitly named and directionally defined.

☐ Calibration and registration are independently repeatable.

☐ Registration error is measured at/near the drilling target, not only at fiducials.

☐ Repeat registration N times and report mean, standard deviation and worst case.

☐ Remove/reseat the template and quantify pose repeatability.

☐ Redock the robot and quantify docking repeatability.

☐ Separate imaging/segmentation, template seating, registration, robot kinematic and tool calibration error contributions where practical.

☐ Define a total allowable error budget before drilling tests.

## 2.7 Robot execution rigidity

☐ Robot can move to a planned pose in a safe phantom workspace.

☐ Tool center point and drill axis are calibrated.

☐ Commanded versus measured pose error is quantified.

☐ Software limits constrain motion to the approved workspace/corridor.

☐ Emergency stop and controlled stop are tested before powered drilling.

☐ Loss of communication or invalid state produces a safe stop.

☐ Dry-run trajectory execution is repeatable before spinning the drill.

☐ Depth-limited drilling into a non-clinical test material precedes tooth/phantom drilling.

## 2.8 Evidence discipline

☐ Every 'works' claim states whether evidence is static, synthetic, developer-live, representative anatomy, printed phantom, or clinical expert acceptance.

☐ Current default dimensions are labelled research defaults unless justified.

☐ Known limitations are recorded instead of hidden by UI automation.

☐ A reproducible test case exists for each critical pipeline stage.

☐ One end-to-end acceptance script/checklist can be run before weekly demonstrations.

# 3. Project Lanes - Keep All of These Alive

Lane | Immediate purpose | Next concrete milestone
A. DENTOBOT imaging/planning | Reliable CBCT -> reviewed anatomy -> approved trajectory | Close representative trajectory + template V0 acceptance; freeze PoC boundary
B. Template / physical interface | Convert anatomy/trajectory into a repeatably seatable reference body | Print, seat, undercut-check, measure repeatability, integrate docking geometry
C. Registration | Establish the patient/template -> robot transform chain | Define frames + registration method; build phantom registration experiment and TRE metric
D. Head-mounted / primary robot | Develop robot capable of executing the approved drill axis | Architecture/DOF/workspace/safety requirements -> first kinematic/mechanical prototype
E. Tooth-mounted robot | Explore compact robot mounted directly to dental reference | Define mechanism architecture, load path, actuation and disposable docking concept
F. Tool / aerotor integration | Make the drill a calibrated controllable end effector | Tool-axis/TCP calibration, depth control, on/off interface, load/thermal constraints
G. Sensing & stop logic | Detect abnormal drilling/material transitions | Pressure/acoustic experiment -> features -> threshold/feedback feasibility
H. Verification / metrology | Quantify total system accuracy and repeatability | Create error budget and bench measurement protocol
I. IP / research outputs | Protect novel sensing/integration concepts and support publications | Capture novelty, experiment evidence, figures and invention claims as work matures

# 4. Tooth-Mounted Robot Design - Questions to Start Now

This lane should progress in parallel even while the main DENTOBOT template closes. The tooth-mounted concept has a different mechanical advantage: the robot and tooth can share a local reference, potentially reducing sensitivity to gross patient/head motion. Its constraints are severe mass, volume, access, sterilization, load and patient comfort.

## 4.1 Functional architecture

☐ What motion does the tooth-mounted robot actually need: pure feed along a preplanned axis, angular correction + feed, or full local positioning?

☐ Can trajectory orientation be fixed by the disposable template so the robot only supplies 1-DOF axial feed?

☐ What DOF are essential versus convenient?

☐ Which component defines the drilling axis: guide geometry, robot mechanism, or both?

☐ How is drilling depth constrained mechanically and in software?

## 4.2 Mechanical load path

☐ Where do drilling axial force, lateral force and motor reaction torque close into the teeth/template?

☐ What maximum load can the support teeth/template tolerate without unacceptable motion?

☐ How much structural deflection can occur before trajectory error exceeds the budget?

☐ Where are the highest compliance joints: template, docking interface, mechanism, bearings, actuator, tool holder?

☐ Can the robot be made statically stiff in the drilling direction even if actuators are small?

## 4.3 Mechanism / actuation

☐ Compare PPP/serial translation, miniature revolute mechanisms, flexures/compliant mechanisms, lead screw, cable, pneumatic or other micro-actuation.

☐ What actuator force, stroke, resolution, speed and backdrivability are required?

☐ How is backlash handled?

☐ Can mechanical hard stops enforce depth?

☐ What sensors are needed for position/force confirmation?

## 4.4 Packaging and clinical interface

☐ What maximum intraoral envelope and mass are acceptable for the PoC?

☐ How will the patient bite/opening constrain access?

☐ How is the robot attached and detached from the disposable template?

☐ Which components are disposable, sterilizable or protected by barriers?

☐ Where do wires/tubes exit without interfering with the clinician?

☐ How is emergency manual removal achieved?

# 5. Registration - First Robotics Problem to Formalize

Registration should become the first explicit bridge from DENTOBOT planning to robot execution. Before choosing a sophisticated algorithm, freeze the coordinate frames and error definitions.

## 5.1 Minimum coordinate-frame model

CBCT/Slicer RAS frame -> tooth/template planning frame -> physical template/docking frame -> robot base frame -> end-effector frame -> bur/tool frame.

The fundamental command problem is to obtain a transform chain that maps the approved Entry/Target trajectory from planning space into the robot/tool frame with a quantified uncertainty.

## 5.2 Registration work package

☐ Draw the complete frame graph and choose unambiguous notation (e.g., T_A_B = pose of frame B expressed in A).

☐ Identify which transforms come from image geometry, template CAD, robot forward kinematics, tool calibration and physical registration.

☐ Choose the first PoC registration method: fiducial-based, template-keyed mechanical registration, optical tracking, probe/contact registration, or a hybrid.

☐ Build a rigid phantom with known target points so registration can be evaluated independently of drilling.

☐ Compute fiducial registration error (FRE) where applicable, but make target registration error (TRE) at the drill target the primary metric.

☐ Repeat registration and template reseating to estimate repeatability and worst-case error.

☐ Propagate the approved trajectory through the transform chain and verify it with an independent physical measurement.

☐ Define what event invalidates the transform and forces re-registration.

## 5.3 Error-budget worksheet

Contributor | Metric to estimate | Initial PoC evidence
CBCT voxel / image geometry | mm | Known spacing + geometry validation
Segmentation boundary | mm | Manual/ground-truth comparison on representative anatomy
Trajectory planning | mm / deg | Dentist repeat placement / reference plan
Template manufacturing | mm | CAD-to-print dimensional check
Template seating | mm / deg | Repeated reseat pose measurement
Template-to-robot docking | mm / deg | Repeated redock measurement
Registration | TRE mm | Independent target-point experiment
Robot kinematics | mm / deg | Commanded vs measured TCP pose
Tool/TCP calibration | mm / deg | Axis/TCP calibration residual
Total system | mm / deg at target | End-to-end target/trajectory measurement

# 6. Near-Term Work Order

☐ Close the clinical questions that directly affect Template V0: insertion direction, allowed support surfaces, undercut tolerance, clearance, wall thickness, margin, sleeve/docking role.

☐ Run representative-anatomy live acceptance and print one template. Treat physical seating as the reality check for the geometry pipeline.

☐ Freeze a PoC Template V0 contract. Stop adding convenience features unless they fix an observed failure.

☐ Draw the registration frame graph and define the first TRE experiment.

☐ Start tooth-mounted robot requirements and mechanism trade study in parallel; focus first on required DOF and load path.

☐ Define the head-mounted/primary robot's first execution milestone: safe dry-run alignment to a planned trajectory on a phantom.

☐ Continue pressure/acoustic sensing as a bounded experiment/IP lane, not a blocker for geometry/registration.

☐ Create one system-level error budget and update it as measured values replace assumptions.

# 7. Weekly Mental-Clarity Board

Question | Green = I know this | Red = next action
What is the current clinical task boundary? | One-sentence procedure scope | Ask Nirav/Varun; record decision
Is the trajectory clinically meaningful? | Dentist approves Entry/Target semantics | Run review on representative tooth
Will the template physically seat? | Printed repeatable seating evidence | Print + reseat/undercut test
Is the template rigid enough? | Measured/no-obvious flex under expected load | Simple bench load/deflection test
Can planning coordinates reach the robot? | Complete frame graph + registration method | Build registration phantom
Can the robot reproduce the axis? | Measured TCP/axis repeatability | Dry-run metrology
Can drilling be stopped safely? | Depth/stop logic + E-stop tested | Bench drill control
What is the dominant error? | Error budget has measured contributors | Measure highest-uncertainty term
What should NOT be worked on? | PoC freeze/deferred list is explicit | Reject feature creep

PoC closure principle: Robust does not mean feature-complete. For this project, robustness means the chosen narrow workflow has explicit inputs, preserved geometry, traceable state, bounded failure behavior, repeatable physical output, and measured accuracy sufficient to connect to registration and robot execution.

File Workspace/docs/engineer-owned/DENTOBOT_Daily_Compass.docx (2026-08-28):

LIVING RESEARCH WORKBOOK

DENTOBOT Daily Compass

One editable operating picture for daily focus, questions, evidence, and handoff

Open this first. Write freely in the yellow cells, tick boxes, paste meeting notes, and change priorities. This is your OneNote-like working memory, deliberately shorter and more operational than the formal engineering record.

Control | Current value
Last reconciled | 28 August 2026
Current phase | Priority-0 Step 6 simulation stabilization: audit collision geometry, diagnose the exact partial-path failure, and expose a guarded three-stage preview. Verification is operator-led and simulation-only.
Formal sources | Project Context · Architecture · Development Plan · Decisions · Tasks · Reproducibility · dated logbooks
Detailed gap source | Research-to-Clinical Gap Closure & Engineering Rigidity Checklist, August 2026

## Today at a glance

Prompt | Your update
Date / location | 28 August 2026 · IITM Ubuntu development workstation
Today’s one sentence | Stop treating a MoveIt percentage as the answer; make geometry, frames, and the first failing robot state visible before optimization.
Outcome 1 | Reset the Priority-0 strategy to collision audit → structured diagnostics → explicit three-stage motion.
Outcome 2 | Record that the current forehead plane/base snap is circular and cannot support a reachability or placement claim.
Outcome 3 | Reconcile the Daily Compass and controlled task tracker so Now, Next, and Future are obvious again.
Do not work on | Planner tuning to force x4 to pass; automatic base optimization; broad diagnostic scripts; physical registration, hardware motion, or drilling.

## Fast capture inbox

Unsorted notes — organize during reconciliation

The project has moved beyond the earlier save/restore and Viewer firefighting. Those paths are substantially stabilized at software level, although normal-window and active-ROS lifecycle acceptance still have open items.

The key present insight is that x4's 44.44–45.34% Cartesian result is a symptom, not a causal diagnosis. The current API hides the adjacent last-valid/first-invalid states, and the current mount plane is not an independent forehead or mechanical-mount datum.

The next useful milestone is an operator-visible diagnostic loop that shows the exact collision payload, robot state, joint margins, IK/continuity result, and failure boundary without weakening safety rules.

Control rule: this workbook is editable working memory, not clinical approval or engineering authority. Unreviewed notes do not silently become accepted requirements.

1 · NORTH STAR AND CURRENT TRUTH

# What DENTOBOT is trying to prove now

PoC closure principle. Robust does not mean feature-complete. The narrow workflow must have explicit inputs, preserved geometry, traceable state, bounded failure behavior, repeatable physical output, and measured accuracy sufficient to connect planning to registration and robot execution.

## Current end-to-end workflow

☐ CBCT import and geometry inspection.

☐ External segmentation; human review and correction of authoritative anatomy.

☐ Manual or assisted Entry→Target creation using the same world-RAS line contract.

☐ Target/occlusal frame plus provisional guide and four independent docks.

☐ Visible erupted support, insertion direction, undercut/blockout, patient-contact shell.

☐ One unified shell + guide + reinforcement + channels + docks model.

☐ PASS/WARNING/FAIL verification and one atomic STL.

☐ Next bridge: physical seating, registration/TRE, robot/tool metrology, safe dry run.

## Honest evidence ladder

Label | Minimum meaning | Does not by itself prove
Static | Source/document/state inspection | Runtime behavior
Synthetic | Automated generated-data verification | Representative anatomy or fit
Developer-live | Observed application workflow | Clinical acceptance
Representative anatomy | Relevant governed CBCT/scene | Manufactured seating
Printed phantom | Fabrication, seating, dimensions, repeatability | Patient safety or efficacy
Clinician/expert | Explicit acceptance question reviewed | Unmeasured system accuracy

## Current truth — edit when evidence changes

Implemented and strong | Implemented; deeper evidence due
Transactional .dentocase restore; freely selectable stages after restore; Step 6 Viewer crash fix; corrected inferior TMJ opening direction; simulation-only MoveIt guard; fail-closed rejection of partial drilling. | Representative condylar/crown landmark review; exact collision-payload audit; last-valid/first-invalid motion diagnosis; valid mount-frame semantics; tool fit, physical seating, registration, TCP and metrology.
Known failure / blocker | Explicitly deferred
Opaque partial Cartesian failure; circular mount-plane/base snap; unverified TMJ landmark subregions/MPR review; active-ROS New Case abort; saved 2.0 mm burr versus 1.5 mm guide bore. | Automatic base optimization and multi-tooth sweeps until diagnostics are trustworthy; full canonical frame refactor and physical registration until later tracks; interactive gap slider until Priority-1 safeguards; New GUI aesthetics until Priority 3.

Safety boundary: no robot motion, drilling, patient-facing, or safety-critical operation is authorized by this planning workbook. Planning and topology results do not authorize drilling.

2 · CLINICAL CLOSURE WORKSHEET

# Decisions that must become explicit

For each row, enter a numeric threshold, a bounded qualitative test, or “deferred” with a reason and revisit trigger.

## Procedure and trajectory

Question | Owner / status | Decision, evidence, or next action
Exact automated task and explicit out-of-scope work | [ ] | [Type here]
Clinician approval; stop, re-plan, re-register, abandon events | [ ] | [Type here]
Required anatomy and hard no-go structures | [ ] | [Type here]
Anatomical meaning of Entry and Target | [ ] | [Type here]
Bur diameter/depth, straight-line assumption, remaining dentin | [ ] | [Type here]
Allowed planning translation/angle error; assisted-plan acceptance | [ ] | [Type here]

## Template V0

Question | Owner / status | Decision, evidence, or next action
Support/retention surfaces and excluded surfaces | [ ] | [Type here]
Insertion direction and acceptable undercut engagement | [ ] | [Type here]
Clearance, wall, crown coverage, support-tooth count | [ ] | [Type here]
Gingival/cervical margin and boundary-edit acceptance | [ ] | [Type here]
Seating force, rocking/gap, removal, repeated cycles | [ ] | [Type here]
Printer/material/orientation/process/dimensional acceptance | [ ] | [Type here]

## Guide, docking, registration, and control

Question | Owner / status | Decision, evidence, or next action
Sleeve versus docking reference; channel/bore dimensions | [ ] | [Type here]
Landmark role versus load-bearing dock role | [ ] | [Type here]
Frame chain and re-registration invalidation | [ ] | [Type here]
TRE tolerance and independent measurement | [ ] | [Type here]
Depth limit, corridor, stop trigger, latency, E-stop/override | [ ] | [Type here]

3 · PRIORITY AND DEEP-DIVE BOARD

# What to work on next

## Priority stack

Horizon | Work package
Now | Quarantine the circular base snap, use only a labelled manual simulation base, and implement Track B collision geometry/payload audit.
Next | Track C structured per-candidate/per-stage diagnostics, followed by Track D strict PreEntry, terminal Entry, and guarded drilling stages.
Later | Priority-1 TMJ/crown/MPR safeguards; Priority-2 restore review and jaw-gap preview; Template V0 representative/physical evidence; Priority-3 GUI.
Not now | Unlimited planner/tolerance search; automatic base optimization; broad frame refactor; batch tooth studies; physical registration, hardware homing/execution, drilling, or clinical claims.

## Default fast-track order

☐ Freeze the clinical task boundary and Template V0 assumptions.

☐ Run one representative end-to-end planning/template case.

☐ Print, seat, remove, reseat, load, and measure Template V0.

☐ Formalize the frame graph and first TRE experiment.

☐ Keep robot/tool/sensing requirements alive in parallel.

☐ Update the total error budget from measured results.

## Deep dives on work already “done” in software

Subsystem | Question before a stronger claim | Evidence
Segmentation/display | Are native masks, optional smooth preview, CBCT quality, artifacts, and uncertainty acceptable for the task? | [ ]
Manual/assisted trajectories | Are Entry/Target meaningful, repeatable, MPR-correctable, and safely invalidated after edits? | [ ]
Visible support ROI | Does the boundary exclude roots/gingiva surrogates and retain accessible fitting surfaces? | [ ]
Undercut/shell | Does the guide seat, resist rocking, remain removable, and preserve printed clearance? | [ ]
Docks/guide holes | Are channels open/aligned, docks rigid/dimensional, and load paths defensible? | [ ]
Scene persistence | Can reopened scenes switch/backtrack without stale, mismatched, or orphaned descendants? | Current; review due
Final verification/STL | Which checks are computational, anatomical, print, registration, or clinician evidence? | Physical evidence due

Observed failure rule. A convenience/visualization task may jump the queue only when an observed defect prevents the bounded representative, physical, registration, or metrology test. Record the blocked acceptance check.

4 · PARALLEL LANE BOARD

# Keep the whole system visible

Status: Active · Waiting · Blocked · Deferred · Evidence due

Lane | Immediate purpose | Current state / next concrete milestone
A · Imaging / planning | Reviewed anatomy → approved trajectory | Trajectory/template software is mature; Priority-1 TMJ/crown/MPR and representative acceptance remain.
B · Template / physical | Repeatably seatable reference body | Unified template exists; correct burr/bore mismatch, then print, seat, reseat and measure Template V0.
C · Registration | Template/tooth → robot transform chain | Deferred until simulation diagnosis stabilizes; define frame graph, phantom and TRE protocol before motion.
D · Head-mounted robot | Execute approved drill axis | Priority-0 Step 6 collision audit, diagnostics and three-stage simulation; no hardware execution.
E · Tooth-mounted robot | Compact robot on dental reference | Future mechanism lane; retain DOF, load-path and docking questions without active implementation.
F · Tool / aerotor | Calibrated controllable end effector | TCP remains provisional; physical tool-axis calibration, depth limiting and load/thermal evidence are future.
G · Sensing / stop | Detect abnormal transitions | Pressure-monitor bench remains separate evidence only; stop logic and controller integration are future.
H · Verification / metrology | System accuracy and repeatability | Persist diagnostic evidence now; total-system error budget and physical metrology follow representative work.
I · Research / IP | Novelty, evidence, figures, claims | Capture architecture and evidence after stable milestones; do not publish clinical or hardware claims from simulation.

## Tooth-mounted robot questions — keep alive in parallel

Theme | Working notes / decision needed
Functional architecture | [1-DOF feed? angular correction? full local positioning?]
Load path and stiffness | [Axial/lateral/torque closure; deflection budget]
Mechanism / actuation | [Stroke, force, resolution, backlash, hard stops]
Packaging / clinical | [Envelope, mass, access, barriers, emergency removal]
Two trajectories | [Reindex, angular adjustment, parallel constraint, or separate poses]

## Lane review note

What moved? What lane disappeared? What is its next smallest deliverable?

Focus moved from forcing one MoveIt case to pass toward building a trustworthy diagnostic simulation framework.

Save/restore, modular continuation, Step 6A direction and Viewer integrity improved substantially. Collision transfer, failure classification, mount semantics and representative/physical evidence are now the limiting work.

5 · TEMPLATE V0 EVIDENCE WORKSHEET

# From watertight mesh to physical reality

## Representative software run

Item | PASS / WARN / FAIL | Evidence or failure note
Reviewed segmentation and source pairing | [ ] | [Type here]
Trajectory correction, locking, and MPR | [ ] | [Type here]
Support patch excludes root/subgingival anatomy | [ ] | [Type here]
Insertion direction and undercut current | [ ] | [Type here]
One occupied watertight/manifold final model | [ ] | [Type here]
Guide channels and four dock bores open | [ ] | [Type here]
MRB reopen and upstream invalidation | [ ] | [Type here]
One STL reopens at expected scale/topology | [ ] | [Type here]

## Manufacturing record

Field | Value | Field | Value
Printer / process | [Type here] | Date / operator | [Type here]
Material / lot | [Type here] | Layer / resolution | [Type here]
Orientation / supports | [Type here] | Post-processing | [Type here]
Source / case | [De-identified] | STL hash | [Type here]

## Physical seating and rigidity

Check | Method / N | Result and acceptance
Terminal seating without excessive force | [ ] | [Type here]
Rocking / gap at full seating | [ ] | [Type here]
Repeat pose over insert/remove cycles | [ ] | [Mean / SD / worst]
Removable without locking or fracture | [ ] | [Type here]
Shell flex under expected load | [ ] | [Type here]
Dock/guide rigidity relative to shell | [ ] | [Type here]
CAD-to-print critical dimensions | [ ] | [Planned / measured / error]

Reality check. CBCT surfaces, offsets, voxel Booleans, and software undercut processing are hypotheses about physical fit until a printed guide is seated and measured.

6 · REGISTRATION AND TOTAL ERROR BUDGET

# How planning coordinates reach the robot

## Frame graph

From → To | Transform source | When measured | Invalidation / evidence
RAS → tooth/template plan | [Type here] | [Type here] | [Type here]
Plan → physical template/dock | [Type here] | [Type here] | [Type here]
Physical dock → robot base | [Type here] | [Type here] | [Type here]
Robot base → end effector | [Type here] | [Type here] | [Type here]
End effector → bur/tool | [Type here] | [Type here] | [Type here]

## First registration experiment

Prompt | Working definition
Method | [Fiducials / keyed dock / optical / probe / hybrid]
Rigid phantom / known targets | [Type here]
Primary metric | Target registration error at/near drilling target
Repeat protocol | [Registration N; reseating N; redocking N]
Acceptance | [Mean / standard deviation / worst-case threshold]

## Total-system error budget

Contributor | Metric | Measurement method | Value / status
CBCT / image geometry | mm | [Type here] | [Type here]
Segmentation boundary | mm | [Type here] | [Type here]
Trajectory planning | mm / deg | [Type here] | [Type here]
Template manufacturing | mm / deg | [Type here] | [Type here]
Template seating | mm / deg | [Type here] | [Type here]
Template-to-robot docking | mm / deg | [Type here] | [Type here]
Registration | TRE mm | [Type here] | [Type here]
Robot kinematics | mm / deg | [Type here] | [Type here]
Tool / TCP calibration | mm / deg | [Type here] | [Type here]
TOTAL AT TARGET | mm / deg | [Combination rule] | [Type here]

7 · WEEKLY CLARITY AND DAILY HANDOFF

# Prevent chaos from returning

## Weekly mental-clarity board

Question | Green = I know this | Red = next action
Current clinical task boundary? | [One sentence] | [Owner / date]
Trajectory clinically meaningful? | [Evidence] | [Next test]
Will Template V0 physically seat? | [Evidence] | [Next test]
Template/dock rigid enough? | [Evidence] | [Next test]
Can planning coordinates reach robot? | Not established: the current percentage is not causal evidence | Complete collision audit and first-failure diagnostics before repositioning conclusions
Can robot reproduce the axis? | [Metrology] | [Next test]
Can drilling be stopped safely? | [Evidence] | [Next test]
What is the dominant error? | [Measured contributor] | [Measurement due]
What should not be worked on? | Hardware execution, clinical use, auto-base optimization and broad GUI polish | Reject work that bypasses the Priority-0 diagnostic sequence

## Daily note block — duplicate as needed

Prompt | Daily record
Date / session | 28 August 2026 · planning and reconciliation session
Intent | Recover a clear mental model after a long implementation stretch and set one defensible development order.
What happened | Reviewed the current Step 6 implementation scope, controlled project documents, task priorities and latest evidence. Separated symptom from cause: x4 is a negative diagnostic fixture, not proof of a collision, base or mechanical workspace defect. Promoted collision audit, structured motion diagnosis and three-stage planning into the controlled Priority-0 strategy; no runtime or hardware action was performed.
Evidence level | Static planning/documentation reconciliation
Decision / new question | Diagnose before optimization. Keep the forehead-mount note unprioritized, but quarantine its circular snap as a Priority-0 dependency.
Failure / limitation | No collision audit, diagnostic UI or three-stage refactor has been implemented yet. Representative anatomy, physical fit, registration, TCP and hardware evidence remain absent.
Next physical action | None authorized. Next work remains simulation/software-only: begin Track B after the flawed base snap is visibly quarantined.

8 · RECONCILIATION PROTOCOL

# How to use this workbook with Codex

☐ Edit this DOCX directly. Keep incomplete ideas in yellow cells.

☐ Ask: “Read and reconcile the DENTOBOT Daily Compass.”

☐ Codex compares your edits with repository state and the controlled documents.

☐ Contradictions, unsafe assumptions, and ambiguous clinical thresholds are surfaced rather than guessed.

☐ Confirmed decisions, tasks, and evidence are written into the correct controlled Markdown file and today’s logbook.

☐ Git and Google Drive are synchronized only when you explicitly approve that batch.

## Meeting / clinician notes

Date, people/roles, question asked, answer/evidence, follow-up owner

[Type here]

## Handoff note for the next session

What future-you or Codex must know before touching the project again

Start from the project tracker dashboard and Priority-0 Development Plan, not the old dated Next section in TASKS.md.

Do not resume planner tuning or broad diagnostic scripts. Preserve x4 as the exact negative fixture, expose the collision payload and first failing state in the normal DENTOWorkflow UI, and keep Execute hidden.

The immediate manual simulation-base datum is only a diagnostic control. It is not forehead truth, registration, or completion of the future mount-frame workstream.

## Decisions waiting for promotion into controlled docs

Draft decision | Evidence / owner | Promote?
Choose the numeric Stage-2 terminal tip/contact tolerance | Requires Track B/C evidence and operator review | Later
Define the physical base_link-to-mount-face transform | Requires actual mount CAD, contact side/normal and allowable offset/tilt | Later
Select the bounded MRML representation for diagnostic sessions | Implementation design; must preserve fingerprints and exclude live ROS state | Later

Data hygiene. Do not enter patient identifiers, credentials, tokens, or non-anonymized medical data in this workbook.

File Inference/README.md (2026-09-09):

# DENTOBOT inference backend

## Purpose

This package is the Linux/WSL2 compute layer for the DENTOBOT research
workflow. 3D Slicer owns the user interface, MRML scene, visualization, and
result review. This package owns dependency-heavy image processing and AI
inference. It does not import Slicer and must not be installed into Slicer's
embedded Python environment.

The validated Windows/WSL Bridge C baseline uses DENTOBOT backend 0.2.0,
TotalSegmentator 2.16.0, PyTorch 2.10.0 with CUDA 13.0, and Python 3.10.20.
The active Ubuntu baseline uses the same backend/TotalSegmentator version with
Python 3.12.13 and PyTorch 2.10.0+cpu. Each platform uses its own pinned
manifest; these profiles are not interchangeable.
The authoritative installation, evidence, recovery, and traceability procedure
is [REPRODUCIBILITY_AND_TRACEABILITY.md](../docs/REPRODUCIBILITY_AND_TRACEABILITY.md).

## Reproducibility scope

The files under `requirements/` pin the top-level versions observed during the
successful 2026-07-23 Bridge C run. They are a validated compatibility
baseline, not a complete transitive lock. `validated-environment.json` records
the corresponding machine-readable runtime evidence. A full platform-specific
environment export remains a release task.

## Runtime profiles

### Windows 11 + WSL2 CUDA

- Windows with WSL2 and the Ubuntu distribution
- a working Windows NVIDIA driver exposed to WSL2
- Conda in WSL2
- the repository available inside WSL, for example under `/mnt/e/...`
- model-cache and run-artifact storage with sufficient free space

Do not install a Linux NVIDIA display driver inside WSL. DENTOBOT uses the
CUDA support exposed by the Windows driver and the CUDA runtime supplied by
the official PyTorch wheel.

### Ubuntu CPU

- Ubuntu with the repository's current container/SlicerROS2 workspace
- Python 3.12 with `venv` support
- the pinned `requirements/ubuntu-cpu*.txt` manifests
- the prepared model cache mounted below `/workspace/data/model-cache`

The Ubuntu launcher and `Infrastructure/install_ubuntu_backend.sh` own this
profile. It invokes the backend directly as a Linux child process and requests
`cpu`; it does not route through WSL.

## Validated Windows/WSL installation

Run these commands from `Inference/` in a WSL shell:

```bash
conda env create -f environment.yml
conda activate dentobot

python -m pip install \
  --index-url https://download.pytorch.org/whl/cu130 \
  -r requirements/pytorch-cu130.txt

python -m pip install \
  --constraint requirements/validated-constraints.txt \
  -r requirements/runtime-validated.txt

python -m pip install --no-deps -e .

python -m pip install \
  --constraint requirements/validated-constraints.txt \
  -r requirements/test-validated.txt
```

If the `dentobot` environment already exists, inspect or remove it deliberately
before recreating it; do not overwrite a working research environment without
capturing its specification.

## Model preparation

Model acquisition is an explicit terminal action and never occurs when Slicer
launches inference. On TotalSegmentator **2.16**, the CLI task names
`teeth` / `craniofacial_structures` are **not** accepted by
`totalseg_download_weights -t`. Use the lab helper (preferred) or the Python
API task IDs **298 → 115 → 113**:

```bash
# Lab / Ubuntu overlay (idempotent; reads .dentobot.env)
Workspace/scripts/install-lab-model-cache.bash
# Windows:
# Workspace\scripts\install-lab-model-cache.bat
```

```bash
export TOTALSEG_HOME_DIR=/path/to/data/model-cache/totalsegmentator
python - <<'PY'
from totalsegmentator.python_api import download_pretrained_weights
for task_id in (298, 115, 113):
    download_pretrained_weights(task_id)
PY
```

Weights land under `$TOTALSEG_HOME_DIR/nnunet/results/Dataset{113,115,298}_*`.
The DENTOBOT runtime replaces implicit downloading with a cache-only guard.

## Verification

```bash
python -m pip check
python -m pytest
python -m dentobot_inference health --json --require-cuda
```

The health output must report the intended environment interpreter, status
`ok`, CUDA availability, and the expected GPU. The three existing WSL tests
and CUDA health check have passed in the recreated environment. The newer
segmentation failure-path tests are explicitly deferred and are not claimed as
passing.

## Slicer bridge configuration

On Ubuntu, start Slicer through `Workspace/scripts/launch-dentoworkflow.bash`.
On Windows, copy `Workspace/.dentobot.windows.env.example` to the repository
root as `.dentobot.windows.env` and start native Slicer through
`Workspace/scripts/launch-native-windows-steps0-5.ps1`. Both launchers supply the same
adapter/Python/artifact/device contract automatically. The Windows adapter
also supplies the exact WSL distribution. Do not install this package into
Slicer's Python or persist workstation paths in an MRB scene.

Slicer calls the environment by absolute interpreter path. Activating Conda in
a separate terminal does not configure Slicer.

## Backend commands

```bash
python -m dentobot_inference health --json --require-cuda

python -m dentobot_inference roundtrip \
  --input /mnt/c/DENTOBOTRuns/<run-id>/input.nii \
  --output /mnt/c/DENTOBOTRuns/<run-id>/roundtrip.nii \
  --result-json /mnt/c/DENTOBOTRuns/<run-id>/result.json \
  --run-id <run-id>

python -m dentobot_inference segment-teeth \
  --input /mnt/c/DENTOBOTRuns/<run-id>/input.nii \
  --output /mnt/c/DENTOBOTRuns/<run-id>/teeth-segmentation.nii \
  --result-json /mnt/c/DENTOBOTRuns/<run-id>/result.json \
  --run-id <run-id> \
  --device cuda:0
```

`segment-teeth` requires an explicit `--device cpu|cuda:0` in DENTOBOT
launches and does not silently change devices.
Each run retains its input, validated output when successful, and
schema-versioned `result.json` under the selected artifact root. These files
may contain patient-derived data and must follow project data-governance
rules.

## Support boundary

Bridge C is technically verified for one representative real CBCT: inference
completed, 60 labels were imported, and aligned 2D/3D display was produced.
This does not establish anatomical accuracy, clinical suitability, robust
failure handling, cancellation behavior, or MRB persistence. Those items are
tracked as deferred validation work in `docs/DEVELOPMENT_PLAN.md`.

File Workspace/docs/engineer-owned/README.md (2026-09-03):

# Engineer-owned records

This folder separates the engineer's personal operating records from the
AI-maintained development controls under `Workspace/docs/`.

The protected set is:

- `DENTOBOT_Daily_Compass.docx` (local and Drive);
- `IITM Personal Work Journal` (Drive-native); and
- `IITM Dental Drilling Robot — Project Tracker` (Drive-native).

Agents must not read, edit, reconcile, move, export, or synchronize any of
these records unless the user explicitly names the artifact and action in the
current request. Generic development instructions—including resume, plan,
reconcile, update docs, Drive sync, close-day, and postmortem-sync requests—do
not authorize access.

`Workspace/docs/TASKS.md` is different: it remains the AI-maintained,
development-authoritative work order.

The matching Drive parent is `IITM Dentobot/Engineer-owned — manual only`.
Existing Drive file IDs must be retained during any explicitly requested move
or update.

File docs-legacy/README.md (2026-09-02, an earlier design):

# Not current

This directory is a **stale duplicate** of the controlled notes.

Current docs are `Workspace/docs/`, which the Ubuntu overlay exposes as
`~/dentobot/docs`. Do not edit these files for active work.

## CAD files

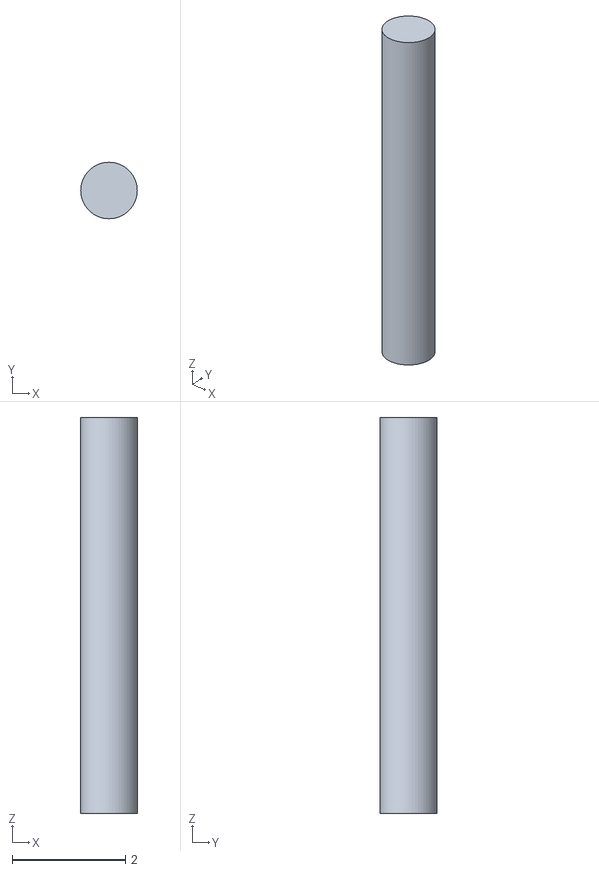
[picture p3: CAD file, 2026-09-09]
dentobot_description/meshes/burr_simulation_1mm.stl
1 x 1 x 7.00

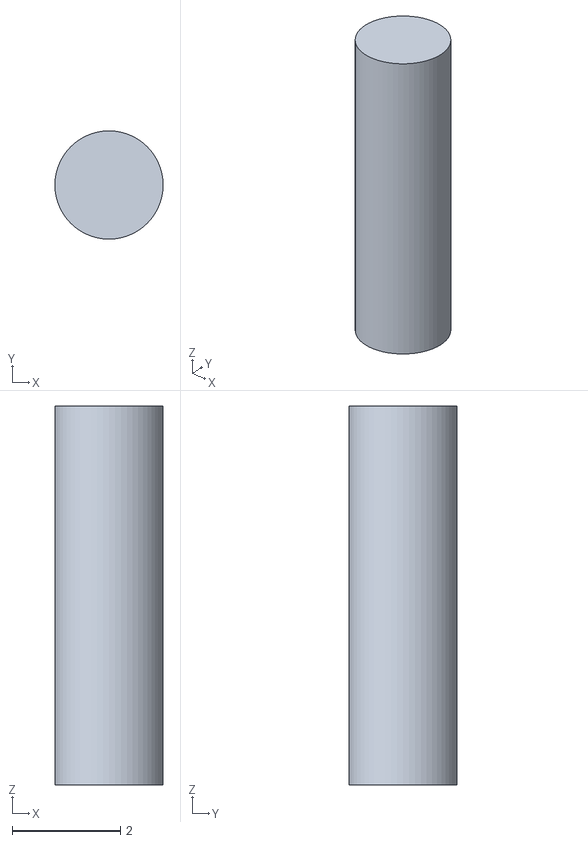
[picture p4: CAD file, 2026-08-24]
dentobot_description/meshes/Step 6 DENTO Robot burr.stl
2.00 x 2.00 x 7.00

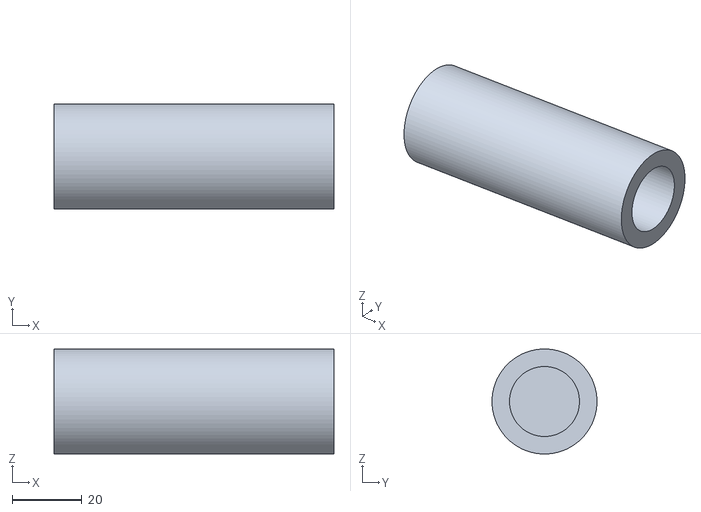
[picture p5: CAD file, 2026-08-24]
dentobot_description/meshes/Step 6 DENTO Robot link-2.stl
80.0 x 30.0 x 30.0

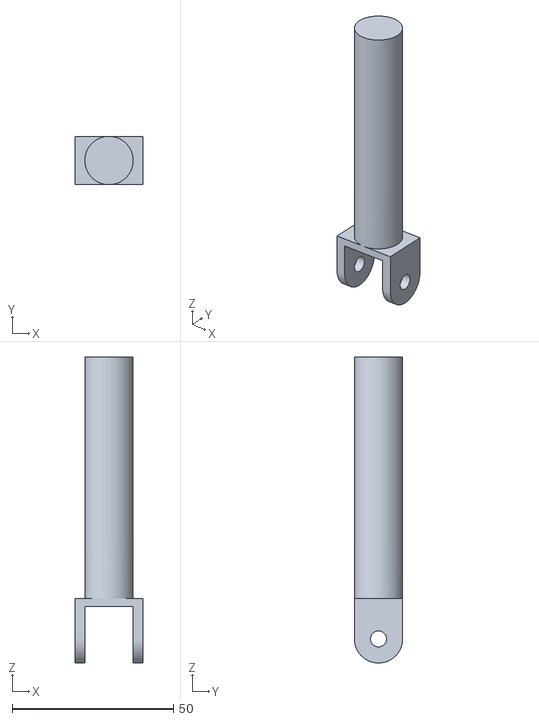
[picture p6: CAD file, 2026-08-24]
dentobot_description/meshes/Step 6 DENTO Robot link-5.stl
21.0 x 15.0 x 95.0

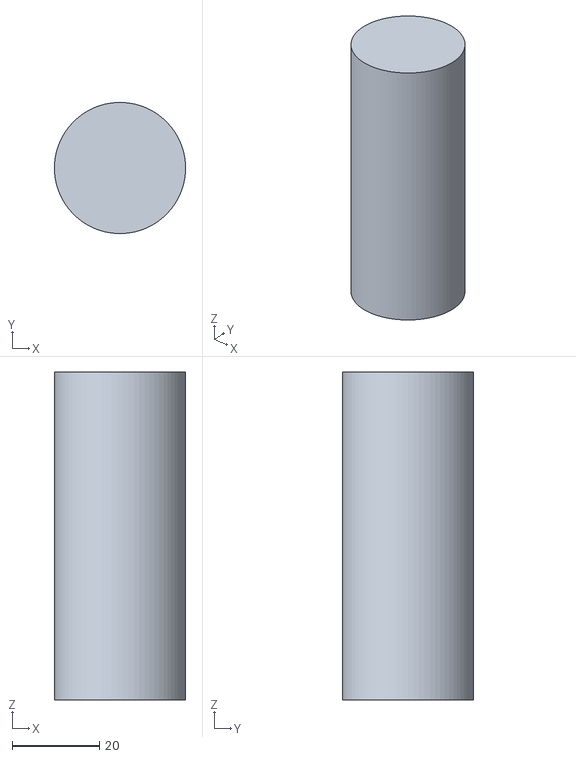
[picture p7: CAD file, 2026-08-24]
dentobot_description/meshes/Step 6 DENTO Robot link-4.stl
30.0 x 30.0 x 75.0

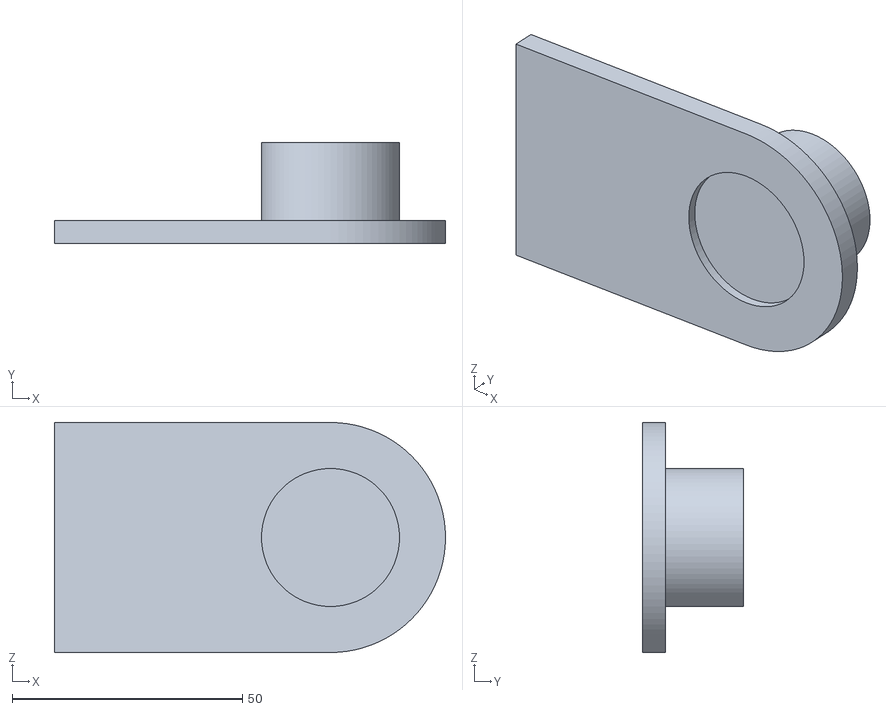
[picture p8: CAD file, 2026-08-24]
dentobot_description/meshes/Step 6 DENTO Robot link-1.stl
85.0 x 22.0 x 50.0

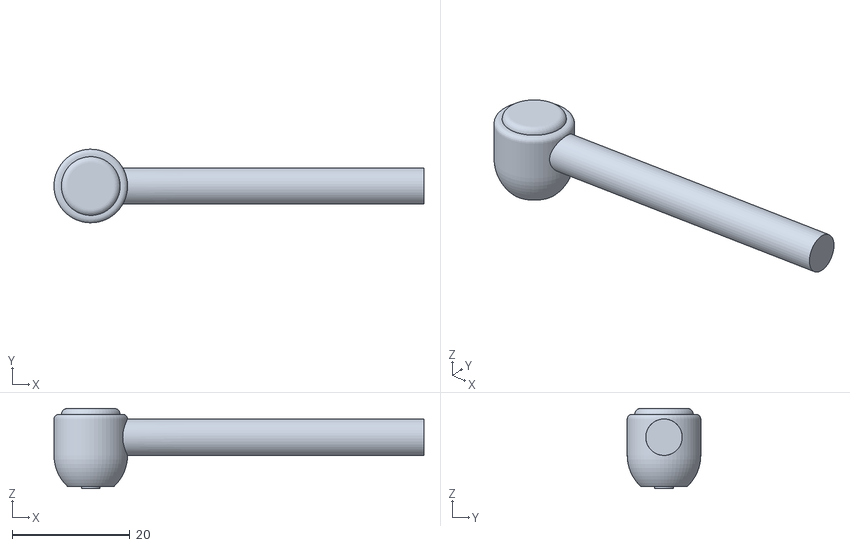
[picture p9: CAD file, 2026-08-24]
dentobot_description/meshes/Step 6 DENTO Robot pneumatic_spindle-Copy.stl
63.0 x 12.5 x 13.6

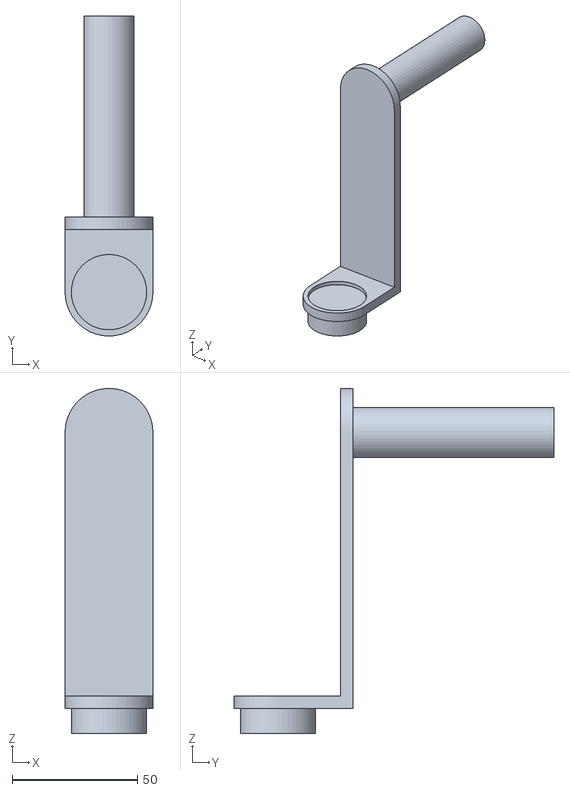
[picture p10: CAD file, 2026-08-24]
dentobot_description/meshes/Step 6 DENTO Robot link-3.stl
35.0 x 127.5 x 137.5

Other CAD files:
dentobot_description/meshes/pneumatic_spindle-Copy.stl
dentobot_description/meshes/link-3.stl
dentobot_description/meshes/link-1.stl
dentobot_description/meshes/burr.stl
dentobot_description/meshes/link-2.stl
dentobot_description/meshes/link-4.stl
dentobot_description/meshes/link-5.stl

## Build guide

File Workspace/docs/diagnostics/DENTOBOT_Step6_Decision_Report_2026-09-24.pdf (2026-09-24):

DENTOBOT | Decision report | 2026-09-23 | Research simulation only | 1

# DENTOBOT Step 6 Planner Recovery & Simulation Studio Foundation

# A-Z implementation, evidence and decision report

### S6-LIVE-01 | FDI21 / FDI31 | 23 September 2026

Prepared for Tarun to review before selecting the next development and runtime action.

CURRENT DISPOSITION: runtime paused; no completed two-target, three-planner comparison; native FDI21 Stage-3 collision retained; offline collision-image attribution defect identified and not yet repaired.

Scope: the supplied conversation, development-controlled records, current source checkpoint, retained run artifacts and available screenshots. This is a decision-support report, not a new execution contract or permission to run simulation.

Research simulation only. No hardware motion, drilling authorization, clinical validation or calibrated physical-fit claim.

Repository: /home/light-tarun/dentobot/ros2_ws/src/DentoBot
Branch: cursor-agent/dentoworkflow-debug-20260918
HEAD at report preparation: 48ad8a8e488f396e52f8ed8bbaba679e2e6b4e99
Working tree: dirty, with comparison and diagnostic changes not represented by HEAD alone.

DENTOBOT | Decision report | 2026-09-23 | Research simulation only | 2

# Abstract

The original problem was a collision-aware Home-to-PreEntry connectivity failure in an FDI31 case. The discussion subsequently exposed several different problems: diagnostic-URDF launch and profile compatibility, persistent per-target guide lineage, stale motion evidence after switching targets, the distinction between IK reachability and collision-valid motion, and the cost and observability of a three-planner comparison. They are related prerequisites, but they are not one planner defect.

Operator trials demonstrated that an altered FDI31 setup could complete all three planning stages with spindle collision enabled after changes to mouth opening, Task Home and robot-base placement/orientation. That is meaningful feasibility evidence for that particular setup. It does not identify which change was causal, validate another target, or establish a reproducible canonical baseline without the exact adjusted case.

The latest timed FDI21 run completed one RRTConnect trial: Stage 1 and Stage 2 passed, but the independent Stage-3 guard rejected target-tooth versus pneumatic-spindle contact. RRT began but was interrupted by the 20-minute batch cap; RRT* had no completed result. Approximately 813 seconds across eight waypoint-guard calls dominated the approximately 874-second RRTConnect trial. This is not a fair comparison of the three planners.

The attempted offline contact pictures were rejected by the operator because they did not show the reported collision. A source audit then found that the recapture script applied the lower-jaw opening transform to the fixed upper FDI21 tooth. Correcting that evidence path is the immediate bounded implementation step. It is not yet a fix for native collision or planner feasibility.

The recommended decision path is finite and causal: repair evidence attribution; reconcile one exact rejected state; determine which geometric/kinematic constraint blocks insertion; consider only mechanism-backed base/Home changes within declared constraints; then optimize measured repeated guard work and complete the frozen-input comparison. Manual tuning until green is rejected as the main development strategy. A useful Studio must also report credible failure or uncertainty, not manufacture universal success.

DENTOBOT | Decision report | 2026-09-23 | Research simulation only | 3

# How to read this report

Read Sections 1-5 for the current status and history, Sections 6-12 for technical diagnosis and options, and Sections 13-16 for the implementation boundary, decision gates and evidence references. The screenshot atlas follows, with a separate caption and limitation for each image. A final source appendix preserves detailed run chronology from the logbook.

### Evidence labels

OPERATOR OBSERVATION: what Tarun reported or visibly demonstrated. SOURCE FINDING: behavior identified in code or serialized records. RUNTIME EVIDENCE: a recorded run outcome, bound to its inputs. SOURCE-COMPLETE: implemented and checked in isolation, not accepted end to end. HYPOTHESIS: a plausible explanation or adjustment not yet demonstrated. PROPOSED: a future action, not implemented or newly authorized.

### Completeness and limitations

This is an exhaustive thematic account of the supplied discussion and available relevant records, not a certified verbatim export of every past assistant response. Some earlier turns are represented by preserved logbook entries and conversation continuity rather than complete raw transcripts. Undated chat messages are sequenced, not assigned invented times. Missing results remain missing; screenshots are not treated as proof of unseen steps.

### Document authority

The canonical execution contract remains docs/diagnostics/FDI31_GUI_PLANNER_P0_PLAN_2026-09-21.md. This report is a dated evidence snapshot. It creates no parallel pending queue and grants no new runtime or geometry-change authority. Later task-specific operator decisions supersede older generic paragraphs in the records. Engineer-owned journals and trackers were not read.

### Reading map / contents

Abstract: p. 2. Goal and status: pp. 4-5. Chronology: pp. 6-8. Runtime ledger: p. 9. Current blocker:
p. 10. Invalid-image root cause: p. 11. Timing: p. 12. Base/Home reasoning: p. 13. Differential diagnosis: p. 14. Recommended gates and rejected paths: pp. 15-16. Implementation and Studio: pp. 17-18. Decision checklist: p. 19. Exact artifacts, joints and sources: pp. 20-22. Screenshot atlas: pp. 23-52. Detailed run chronology: pp. 53-58. Final interpretation: p. 59.

DENTOBOT | Decision report | 2026-09-23 | Research simulation only | 4

# 1. Outcome sought and present position

### Operator objective

Prepare multiple target-tooth trajectories and respective guides in one subject case; switch between completed guides without unrelated staleness; verify the selected guide at Step 5C; activate its PreparedBranch; run Step 6 simulation and retain all diagnostic evidence. Ultimately a non-engineer dentist should be able to operate a robust multi-trajectory Simulation Studio, with the engineering complexity handled by the product.

### Immediate comparison contract

One Compare Three Planners action runs configured RRTConnect, RRT and RRT* sequentially against identical target, base, Task Home, acknowledged scene and settings. Default settings are one attempt and 5.0 seconds per native joint-planning request. Ordinary planning or guard failures are retained; fatal runtime/identity failures and cancellation leave explicit NotRun rows. No automatic winner or motion authority is created.

### Where we actually stand

The comparison action, branch-keyed persistence, report UI and display-only replay have a recorded source implementation and focused checks. Runtime acceptance is incomplete. The latest FDI21 record is a checkpoint, not a completed saved comparison case. FDI31 continuation and ROS-disconnected reopen acceptance of a completed comparison have not followed. The screenshot attribution defect is the immediate blocker to informed human geometry review.

### What a successful foundation means

Success is not that all 96 registry slots or roughly 100 proposed trajectories must pass. Success means a reproducible, auditable system that distinguishes feasible tasks, demonstrated constraints, not-yet-demonstrated feasibility and inconclusive input/evidence. It must make adjustment advice understandable without hiding failed attempts or altering the task silently.

DENTOBOT | Decision report | 2026-09-23 | Research simulation only | 5

# 2. Status at a glance

Area | Current evidence and remaining boundary
FDI31 canonical recovery | Historical P1 failure; diagnostic housing-off P1 pass; operator alternate-base housing-on full-chain pass. Exact altered working scene not independently reproduced; canonical milestone closure remains open.
FDI21 guide / branch setup | Two-target regeneration, alternating selection and fresh reopen have recorded headless successes. User reported working verification; broad normal-window acceptance must not be inferred from unrelated planner screenshots.
Planner controls | RRTConnect, RRT and RRT* configured; attempts/time controls; tooltips and reopenable error text. Operator confirmed tips and retained message. Approximate IK locked off; Cartesian Stage 2/3 still locked on.
Three-planner batch | Source implemented and focused checks recorded. Full three-row meaningful runtime comparison for FDI21/FDI31 is not complete.
Latest FDI21 r6 | RRTConnect Stage 1/2 pass, Stage 3 native collision; RRT interrupted; RRT* no completed result; overall timeout.
Collision pictures | Three offline capture attempts; final images rejected. Fixed-upper tooth incorrectly jaw-transformed by recapture script. Source-only bounds check exists; repair and corrected runtime evidence pending.
Time cost | Waypoint guard dominates measured first trial. Increasing timeout adds capacity, not geometric feasibility or algorithm correctness.
Studio / full cycle | Scheduler not built in this pass. Guarded Drill, Return Home, repeatability and complete saved replay acceptance remain separate gates.

DENTOBOT | Decision report | 2026-09-23 | Research simulation only | 6

# 3. Chronology I - from FDI31 recovery to geometry

### Sep-19 baseline and Experiment A

The starting branch/revision supplied by the operator was b79161d93fd37a2ba2fee67703a8229cdf43689b. The sole original runtime case was dentobot-case-sep19-step6.dentocase. Established evidence: collision-aware J1-J5 PreEntry endpoints existed, but Home-to-PreEntry P1 connectivity failed; P2/P3 did not run. J6 and PreEntry-IK theories were not to be reopened without contrary evidence.

### Narrow diagnostic change

Experiment A required a checked-in copy of canonical dentobot.urdf with exactly the complete pneumatic_spindle-Copy_collision block removed. One default-off simulation option selects it before robot_description is loaded, shared by MoveIt, guard, robot-state publication and SlicerROS2. No runtime XML surgery, allowed-collision exemption, geometry tuning or generic harness was authorized.

### Case loading and profile confusion

The operator encountered Step-6 environment/base_setup_fingerprint post-hydration mismatch, grayed ROS controls, and robot-profile incompatibility. The conversation challenged an exclusion workaround after adding the diagnostic URDF altered resource fingerprinting. A subsequent launch handoff issue meant the first purported diagnostic trial still ran canonical housing-on. These are integration/identity issues, not evidence that the housing-off hypothesis failed. The user created a fresh Sep-22 case; old cases remained historical, not silent fallbacks.

### Visible experiment outcomes

Housing-off P1 subsequently passed with 150 waypoints and is labelled M1-DIAG / HOUSING-OFF PASS. It does not close canonical housing-on M1 or authorize housing-off P2/P3. A later close-Home / 45.96-mm opening trial had no tolerance-valid PreEntry IK solution. Another Home at the same gap passed P1/P2 but remained blocked at Stage 3. Base placement/orientation was then changed and an operator screenshot showed a housing-on full chain: 66 / 10 / 22 waypoints, CompletedWithWarnings.

### What that history establishes

The original difficulty was not a single immutable algorithm limitation. Setup influences reachable branches and collision geometry. But changing several inputs across these trials prevents causal attribution to one variable. The operator conclusion that physical space mattered is supported as a working interpretation, not a proof that the spindle is globally too large or that changing the base alone always solves it.

DENTOBOT | Decision report | 2026-09-23 | Research simulation only | 7

# 4. Chronology II - multi-target memory and activation

### The requested workflow

After FDI31 simulation, the operator created an FDI21 trajectory and guide in the same case. Step 5B initially blocked creation with “Choose one current-target trajectory or an explicit pair.” That was repaired sufficiently for the operator to proceed; Step 5C then repeatedly failed “Single current-frame target dock.”

### Why this mattered beyond a button

A guide selector alone was insufficient. Selecting or rebuilding one target made the other stale because working Step 4A/4B/4C state and lineage were not restored or scoped correctly to each PreparedBranch. The repeated FDI21/FDI31 alternation exposed ownership, exact trajectory-set, frame provenance and docking-parameter dependencies. Staleness was useful when geometry genuinely changed; it was wrong when merely inspecting an independent prepared branch invalidated another.

### Implementation direction retained

The branch must own its exact template, trajectory references, docking assembly, normalized docking parameters and relevant provenance. Activation restores branch working state together, transactionally, rather than copying geometry into a second store or disabling stale checks. Shared case anatomy, jaw opening and robot environment remain shared dependencies. A real change to those dependencies can legitimately stale multiple branches.

### Observed milestones and remaining caution

The conversation records repeated failures, then FDI31 Step 5C pass, further FDI21/coexistence corrections, user verification of recent implementation, and a headless Step 4A-through-5C alternating sequence with Step 6A activation and save/reopen. The package FDI21-31-headless-verified-sep22-step6a.dentocase retained both slots Current on fresh reopen. This does not restore live ROS, Home or workspace validity.

### Stale diagnostics were a separate issue

The user then ran FDI21 and saw no PreEntry IK solution while the diagnostics window showed a complete chain. The window explicitly said State: Stale; stale reason: Target tooth changed. It was legacy FDI31 evidence, not a fresh FDI21 success. A later claimed FDI21 manual pass screenshot had the same warning and no current Approach plan. These reports must stay visible but cannot be counted as current-target acceptance.

### Other requests preserved in context

The user also reported Step 4A scroll-wheel and assisted-trajectory regressions, requested a 10-mm rather than 15-mm Step 4C center-to-dock default, and asked for logbook/screenshot preservation and commits. This report does not independently certify each historical edit or commit; these are related requests, not explanations for the current native Stage-3 contact.

DENTOBOT | Decision report | 2026-09-23 | Research simulation only | 8

# 5. Chronology III - controls, batch implementation and evidence

### Planner observability first

The operator requested visible planner identity, a chooser, approximate-IK and Cartesian controls, timing/attempt tips, and shared parameters for Approach (6.5) and Drill (6.6). RRT* was added after the initial chooser omitted it. Tooltips explain locked controls and parameter usage. Approximate IK remains disabled; Cartesian Stage 2/3 remains enabled and locked until an independently checked replacement exists.

### Retained failure text

The user closed a detailed result dialog without saving it and asked to recover the text in Motion Diagnostics. The retained error-dialog text panel was implemented and the operator confirmed it, along with tooltip explanations. Screenshots show Stage 1/2 pass and Stage 3 guard failure even though geometric Cartesian completion is 100%.

### One click, not three manual runs

The user rejected three separate planner operations for every tooth. The approved batch plan requires an identical frozen identity, fresh transient guard/planning context for each trial, cancellation between trials, full diagnostics and exact paths, branch-isolated storage, and non-authorizing replay on reopen. The single-planner control remains for later amendment, with a new live plan required.

### Source checkpoint

The Sep-23 logbook records implementation in DENTOStep6State, DENTORobotWorkflowFacade, DENTORobotSimulationPanel, parameter_state, runtime, widget_robot and widget_robot_shell, plus focused tests. Initial recorded pure suite: 27 passed. Following identity repair: 28 passed. Later timing/source checks were targeted. These are historical recorded results; this report did not rerun the production suite.

### Case correction

An early request said FDI21 and FDI32, and a filename also contained “32.” Inspection showed PreparedBranches for FDI21 and FDI31; the operator explicitly corrected the target pair. The authoritative input became FDI21-31-headless-verified-sep22-step6a.dentocase. Filenames are not target authority; branch lineage determines the actual target.

DENTOBOT | Decision report | 2026-09-23 | Research simulation only | 9

# 6. Runtime attempt ledger - why completion is still open

Run | Outcome / interpretation
FDI21 attempt 1 | Stopped before planning: local MRML robot not loaded; ROS2 module startup warning. Automation setup failure, not planner failure.
r2 | Robot and scene loaded; saved Task Home rejected as belonging to different robot resources after OMPL profile change. No trial.
r3 | Explicitly approved production Home recapture saved a new current-profile case. Comparison then failed identity check; all rows NotRun. Screenshot initially showed main window, not report.
r3 source diagnosis | Scene audit generated_at_utc changed during identical re-acknowledgement. Batch had frozen event identity as content identity. Added stable content fingerprint and retained per-trial audit identity.
r4 | RRTConnect reached Stage-3 tooth/spindle guard failure. RRT and RRT* failed prerequisites because identical scene re-acknowledgement invalidated Home. Not a valid three-planner comparison.
r4 source correction | Preserve prior audit identity only if all fields except timestamp/fingerprint match after fresh acknowledgement. Changed payload/policy/status still invalidates.
r5 | Hit 1200-second cap; no completed result or saved comparison case. Server logs show planner configurations, but no complete per-trial outcome evidence.
r6 | Timing instrumentation and per-trial checkpoint retained completed RRTConnect Stage-3 collision. Guard cost dominates. RRT interrupted; RRT* no completed trial; no full comparison case.
Offline capture 1 / 2 / 3 | First unsupported camera API; second omitted spindle in framing; third showed separated tooth/spindle and was rejected. Source later found upper-tooth jaw-transform defect.

Each run above had its own authorization and recorded stop. Run numbers do not reset a causal retry ceiling. Later FDI31 and completed-record offline reopen checks did not occur merely because a partial output case existed.

DENTOBOT | Decision report | 2026-09-23 | Research simulation only | 10

# 7. Current blocker - exact FDI21 interpretation

### Latest meaningful trial

FDI21 r6 used the canonical housing-on URDF and the separately saved current-profile Home case. The retained representative RRTConnect candidate is index 6, workspace clearance sample 198. Home-to-PreEntry and PreEntry-to-Entry succeeded. Full-task Stage 3 was rejected at composed waypoint 459, drilling sequence 460, interpolation sample 1/1.

### Named pair

dentobot_target_tooth_2.25.156727832881888777359082987559036393993 versus pneumatic_spindle-Copy. This is target anatomy versus spindle housing, not merely permitted burr-to-target contact. The guard rejection must remain a blocker under current policy.

### Why “100%” is not success

Cartesian completion describes how much of the requested path was generated kinematically. Independent full-chain guard evaluation can reject a point on that generated path. Thus a Stage-3 fraction of 100% with Stage-3 Failed is coherent: the requested endpoint was represented, but the path was not accepted. “Approach ready” is not Drill authorization.

### What is and is not known

Known: native guard emitted a non-approved pair at a recorded state; one candidate path and its failure report were retained. Unknown: contact depth/nearest point in r6, exact physical explanation in a corrected visual reconstruction, whether another admissible tool frame/base arrangement avoids the contact, and whether all meaningful arrangements are infeasible. One failed candidate is not a global impossibility proof.

### Independent envelope warning

Requested drilling depth 7.571 mm plus provisional guide/shell traversal allowance 0.500 mm gives 8.071 mm combined insertion. The provisional envelope is 6.500 mm: excess 1.571 mm. Effective modeled tool protrusion is 7.000 mm with a 0.500-mm reserved visible/protrusion margin. This warning is distinct from native collision. It should not be erased by shortening the approved trajectory or increasing an uncalibrated number until green.

### Safety interpretation

These are research-simulation quantities, not measurements of the actual handpiece, guide or patient. The report makes no clinical fit or safe-drilling claim. A new geometry decision needs the operator’s dimensional and physical interpretation, with the existing collision and phase checks preserved.

DENTOBOT | Decision report | 2026-09-23 | Research simulation only | 11

# 8. Why the collision screenshots were invalid

### Operator correction

Tarun explicitly rejected the pictures: the spindle and something resembling the target tooth were visible, but the colliding object was not represented in contact. A picture with the right-looking components is not diagnostic evidence unless it depicts the same object identities, transforms and robot state as the native query.

### Concrete source finding

Testing/run_dentobot_step65_collision_recapture.py obtains the target surface, then unconditionally calls _step6CaseJawPolydataWorld. Production logic_robot_scene_sync.py starts with the original collision surface and applies that transform only when the segment belongs to the moving lower jaw. FDI21 is in the fixed upper set; its saved audit records classification fixed and jaw_transform_application_count = 0. The recapture therefore incorrectly moved the upper tooth.

### Numerical corroboration

Saved correct target world-RAS bounds, mm: X [-99.980, -91.867], Y [-44.774, -33.631], Z [53.930, 77.450]. Invalid recapture: X [-99.511, -91.399], Y [-65.894, -54.356], Z [18.623, 41.046]. Displayed spindle: X [-106.345, -85.794], Y [-40.817, 22.878], Z [38.431, 75.941]. The invalid target has about 13.54 mm Y separation from the spindle. Correct saved target bounds overlap the spindle box in all axes.

### Evidence boundary

Bounds overlap is only a broad spatial consistency check, not triangle contact, penetration or native collision proof. The saved case audit also precedes the r6 acknowledgement, so matching its geometry does not alone certify the r6 native scene. The repair must reconcile the actual collision object/payload, frame and exact evaluated state, not just produce a visually persuasive overlap.

### Immediate source step, not yet done

Use existing fixed-upper/moving-lower classification or the exact audited collision payload in recapture. Do not add a second transformation policy. Check fixed upper remains untransformed and lower receives the opening exactly once. Preserve source anatomy. Reconstruct only display-only evidence, record object IDs and state identity, and fail closed if the required pair/state cannot be established.

### Current protective change

A source-only bounds-overlap check was added to the capture paths to prevent separated models being labelled collision views. It is not runtime-verified and does not solve scene attribution. The known unconditional-transform defect remains present at report preparation. No fourth recapture was run for this report.

DENTOBOT | Decision report | 2026-09-23 | Research simulation only | 12

# 9. Why 5 seconds became a 20-minute run

### Different levels of time budget

The 5.0-second parameter applies to an individual native joint-planning request. One Approach trial can enumerate multiple IK seeds, attempt direct and clearance routes, perform Cartesian preflights, synchronize/prepare guards, and validate full waypoint sequences. Three configured planners repeat this higher-level work. The runner’s 1200-second cap is an outer process limit, not the planner setting.

### Measured r6 timing

Case opened at about 60.4 s; Step 5C verified at 66.5 s; branch activated at 70.5 s; ROS connected at 107.0 s; Task Home validated at 109.5 s. The completed RRTConnect checkpoint appeared at 1050.4 s. Its trial took about 874 s. Eight completed guard_waypoints calls totalled 813.39 s, largest about 141.8 s. Fourteen joint-plan calls totalled about 4.6 s; fourteen Cartesian calls about 21.97 s.

### Interpretation

Guard work was approximately 93% of that trial’s measured duration. These nested instrumentation durations are not independent buckets that should all be added. The evidence points to waypoint validation as the first performance investigation, not simply a slow RRTConnect solver. It does not yet prove which lower-level transport, synchronization, collision query or repeated computation dominates each guard call.

### 20 minutes versus 30 minutes

Raising the cap to 1800 seconds allows 600 more seconds of work before termination. It could permit more trials to finish, but does not remove collision, fix identity, make bad pictures valid or guarantee completion. It may only spend longer repeating rejection. No automatic cap increase is approved by this report.

### Options already discussed

Timing option A: add flushed UTC and monotonic phase/call records and checkpoints; implemented and run as r6. Timing option B: impose a total per-planner trial budget; operator rejected it. Timing option C: optimize only the measured repeated work after evidence, preserving exact validation semantics; not yet implemented. These option names are distinct from historical Task Home Experiment B and the later rejected manual-development Path B.

### Safe performance direction

First attribute cost at the relevant guard boundary; then remove redundant setup/transport or repeated invariant computation only if equivalent inputs and fresh authoritative checks are preserved. Do not cache collision verdicts across changing state, skip waypoints, loosen tolerances, reduce search silently or claim a fair comparison after changing one planner’s budget.

DENTOBOT | Decision report | 2026-09-23 | Research simulation only | 13

# 10. Base, Task Home and mouth opening - causal roles

### Robot base / mount

The base transform changes the target path expressed in the robot frame and can change joint-range feasibility, conditioning, available branches, upstream-link clearance and reachable tool orientation. A small position or orientation adjustment can matter greatly in a constrained five-joint system. A mount proposal must still be anatomically/mechanically admissible; an arbitrary translation is not a clinical mounting solution.

### Task Home

Home changes the initial configuration, approach connectivity and IK seed/branch selection. It is a strong candidate variable when valid PreEntry endpoints exist but P1 cannot connect. If P1/P2 already pass and Stage 3 collides, Home is not automatically the primary lever. It might indirectly select another branch/tool frame, but does not change contact at an identical full world-space housing pose.

### Mouth opening

Increasing the gap moves lower-jaw anatomy and can improve access around it. Upper FDI21 is fixed in the case’s head/world representation. A larger opening therefore does not itself move FDI21 away from the housing; any improvement must come through changed surrounding access or another setup/path change. The measured 45.96-mm gap is an input to study, not a general prescription.

### Axis versus complete orientation

Position-axis IK constrains TCP position and drill axis using J1-J5. Different admissible arm solutions may place non-axisymmetric housing differently around that axis. A base or seed change can alter which solution is found. This is a reason to inspect exact FK and housing pose, not authorization for speculative roll sweeps, J6 planning, new DOFs or relaxed residuals.

### What the operator’s successes contribute

The altered FDI31 full-chain pass is a valuable feasibility witness for its recorded visible setup. Its role is to motivate a causal investigation and, if the exact state is later available, a controlled reference. It cannot become a universal base/Home rule or substitute for current FDI21 evidence.

### Required form of future advice

Every proposed adjustment should state: failed stage, exact observed constraint, why the variable can affect it, what stays fixed, allowable adjustment bounds, what result would refute the hypothesis, and which evidence the operator must review. “Try moving the robot” is not an adequate Studio diagnostic.

DENTOBOT | Decision report | 2026-09-23 | Research simulation only | 14

# 11. Differential diagnosis - do not merge the failures

Observed symptom | Interpretation and discriminating evidence
No tolerance-valid PreEntry IK; collisions empty | No solution found by the bounded solver/seeds at this setup; not proof of collision or global unreachability. Check residuals, joint margins, frames and branch search evidence.
Valid PreEntry endpoint; P1 fails | Endpoint validity is not connectivity. Examine start/goal, direct-segment first collision and bounded native routes. Home/base may matter for different reasons.
P1/P2 pass; P3 native contact | Task-line/branch/housing feasibility is the immediate question. Changing free-space planner cannot by itself remove the same downstream contact.
100% Cartesian fraction; guard fails | Generated path reached its requested extent; independent acceptance rejected it. Do not promote partial/invalid path to Drill preview.
Old complete diagnostics after target switch | Historical stale evidence, not a fresh pass. Match branch, trajectory, task and base fingerprints, not visible tooth labels alone.
Case/profile/Home rejection | Resource or lineage prerequisite failure, not an algorithm result. Do not disable compatibility gates or call NotRun a planner failure.
Separated objects in contact screenshots | Evidence reconstruction/frame mismatch until resolved; cannot overturn native collision or justify geometry changes.
Timeout | Incomplete computation/evidence, not infeasibility. Inspect the last flushed phase and completed checkpoints.

DENTOBOT | Decision report | 2026-09-23 | Research simulation only | 15

# 12. Recommended path A - finite, evidence-led gates

### Gate A1: repair attribution at the smallest scope

Correct the identified upper/lower transform defect and add one focused check. Reuse existing scene classification or audited outgoing geometry. Verify source/target IDs, units and frame chain. Do not rerun three planners to learn whether a fixed upper tooth was wrongly transformed.

### Gate A2: reconcile one retained rejected state

Under a separately approved bounded runtime scope, reconstruct or evaluate the retained first-invalid state against the matching scene. Capture context, pair close-ups and the same state from inferior, apical and oblique views. Preserve joints and audit identity. Outcomes: agreement and contact leads to feasibility reasoning; mismatch leads to the precise scene/state defect; missing data leads to a named instrumentation request, not another blind full run.

### Gate A3: establish insertion feasibility

Inspect the actual approved Entry-to-Target line, housing/burr/guide dimensions, fixed tool frame and relevant joint margins. Separate target contact, upstream collision, limit/reach failure and provisional envelope warning. Determine whether the current branch fails and whether another admissible arrangement is plausibly available. Do not turn a bounded negative search into a universal impossibility claim.

### Gate A4: constrained adjustment only when justified

If evidence identifies a base/Home mechanism, define one controlled comparison with the operator: fixed case/trajectory/policy, one declared variable, admissible range and a discriminating result. Preserve failed and successful configurations. Seek a useful feasible region and margins, not an unexplained single green pose. Manual expertise supplies constraints and interprets geometry; it is not a bypass.

### Gate A5: measured efficiency and batch completion

Once attribution and the relevant feasibility question are settled, implement a bounded optimization of measured repeated guard work if needed. Complete the same-input planner comparison, save a new case, reopen offline and inspect reports/ghost paths while guarded preview stays gated. Only then assess relative behavior; do not label a planner better because a common Stage-3 constraint blocked another trial.

### Stop rule that prevents spiralling

Each action must discriminate named hypotheses and produce a decision. An unchanged unexplained failure is not permission to increase budget, add candidates, move geometry or repeat the entire workflow. Stop at the first decision-critical unknown and return a usable evidence packet with a specific operator question. The three-failure ceiling and manual verdict gate remain.

DENTOBOT | Decision report | 2026-09-23 | Research simulation only | 16

# 13. Rejected paths and valid alternatives

### Rejected development Path B

The recent alternative was to manually adjust the setup until it passed, save a “golden case,” and use it to unblock the rest of the workflow. Tarun rejected this as manipulating values to obtain a desired result. It is not recommended as the main strategy because it confounds variables and provides weak generalization to other teeth or mounting constraints.

### What manual work remains useful

A deliberately documented manual observation can be excellent evidence. A saved successful state can establish an existence witness; a before/after pair can test a named mechanism. The boundary is causal discipline: retain exact inputs, do not discard failures, preserve geometry/guard policy, and never assume a manually convenient mounting pose is physically admissible.

### Alternative if A exposes an actual design constraint

If corrected evidence shows a geometric/tool constraint for the reviewed setup, the appropriate next step is an operator-led design/input review: measured tool protrusion, housing envelope, guide dimensions, mount feasibility or the approved trajectory. That is an explicit changed experiment, not an invisible numerical workaround. The software should report the constraint honestly and preserve the prior result.

### Alternative if evidence remains insufficient

If the exact native state or scene cannot be reconstructed, keep the run Inconclusive and instrument the missing boundary. Do not infer contact depth from pixels or manufacture a “collision-free” result by suppressing a body. A truthful inability to decide is preferable to a persuasive but misregistered image.

### Does A guarantee success?

No. It should guarantee a bounded improvement in knowledge: identify and fix a software defect, demonstrate a constraint for evaluated inputs, justify a specific setup change, or identify missing evidence. It avoids endless trial only if those stop conditions are enforced. A planner cannot promise a feasible path through an impossible geometry.

DENTOBOT | Decision report | 2026-09-23 | Research simulation only | 17

# 14. Implementation map and remaining source boundaries

### Existing comparison and persistence

DENTOStep6State.py owns record/integrity helpers; DENTORobotWorkflowFacade.py runs the ordered comparison through existing Approach planning and retains reports/paths; DENTORobotSimulationPanel.py and widget modules expose comparison, shared parameters and saved diagnostic views. Parameter/runtime state carries branch-keyed records. These source changes are in the dirty working tree and cannot be reproduced from HEAD alone.

### Existing automation

Testing/run_dentobot_step65_three_planner_gui.py drives the production flow, retains setup and per-trial checkpoints, writes timeline.jsonl, captures diagnostics and has a fresh-process reopen mode. It must not select a replacement target by filename, silently repair Home, move the base, run preview or bypass eligibility. Explicitly approved Home recapture was a separate, narrowly gated step.

### Immediate edit candidate

Testing/run_dentobot_step65_collision_recapture.py contains the unconditional jaw transform. The smallest meaningful repair is reuse of the production fixed/moving semantics, with a focused upper/lower check and evidence identity validation. The production planner should not be changed to compensate for a diagnostic renderer bug.

### Exact guard-state preservation

The native guard and DENTOROS2Bridge status already expose evaluated_positions, sample index/fraction, first/second body and world-object evidence. The facade currently retains a waypoint-level requested vector. At the reported sample 1/1 this is the endpoint, but a general interpolated rejection can differ. Reuse the existing native fields if exact-state persistence is needed; do not invent a second state evaluator. Contact/nearest fields are null in r6 and must remain unknown.

### Later work, not bundled into this repair

Cartesian-off primary sequential exact-pose IK, full-cycle Drill/Return Home acceptance, broad Studio scheduling, automated mount optimization and model/resource migration are separate scoped work. No new planner framework, XML-transform framework, database, persistent evidence service or generic harness is needed to fix the known capture error.

DENTOBOT | Decision report | 2026-09-23 | Research simulation only | 18

# 15. Studio foundation - what should survive this work

### One authoritative case, distinct branches

Keep .dentocase as the package authority and MRB as geometry authority. PreparedBranches own their target-specific guide/trajectory/provenance; shared environment changes explicitly invalidate dependent evidence. Switching selection alone must not overwrite another branch’s stored result. Stale evidence stays inspectable and labelled.

### Immutable attempt evidence

Each comparison needs exact branch/task/base/Home/scene/profile identities, settings, requested/configured planner IDs, stage outcomes, exact failure text, complete or last-valid full-precision paths and stage boundaries. Record timing and screenshots at completion of each trial so a later timeout cannot erase earlier findings.

### Offline review is not runtime restoration

Saved paths can produce transient ghost replay at their saved coordinates when integrity and robot/base identity match. They must not move the authoritative robot, publish collision objects, reconnect ROS, restore Home validity or become a guarded plan. A selected planner still needs a fresh current live plan through all gates.

### Dentist-facing result categories

A useful result explains whether the evaluated task is feasible in the reviewed setup, blocked by a demonstrated constraint, not demonstrated under bounded search, or inconclusive due to missing/stale evidence. Advice should separate mounting, Home connectivity, local tool clearance, guide/tool capacity and data-quality problems. The operator should not need to infer these from a generic red error box.

### Scaling boundary

The current registry vision is 32 teeth x 3 trajectory slots; “up to 100” is the broader product aspiration. A batch may share environment setup only while identities remain unchanged. It must not silently move the base per target and call the study one fixed-setup result. The scheduler follows stable single-task semantics and full-cycle acceptance, rather than multiplying current ambiguity by 96.

DENTOBOT | Decision report | 2026-09-23 | Research simulation only | 19

# 16. Decision checklist before authorizing further runtime

### 1. Agree the immediate question

Is the current native FDI21 rejected contact represented correctly in evidence? Not: can another planner eventually turn the task green?

### 2. Freeze the scope

Source repair and focused check first; then one exact-state diagnostic if approved. No three-planner rerun, automatic base/Home movement, tolerance change or new geometry.

### 3. Define acceptable evidence

Same named pair, matching geometry/frame identity, exact rejected state, three usable angles and context, native contact fields where available, unknowns explicitly labelled.

### 4. Define the branching decision

If evidence matches: discuss the physical/kinematic mechanism. If not: repair the exact mismatch. If incomplete: collect only the missing discriminator.

### 5. Preserve the operator’s role

Tarun interprets the geometry and admissible setup constraints. An approval request must include evidence and a concrete choice, not merely ask to continue.

### 6. Do not conflate milestones

Source checks do not close runtime acceptance; a housing-off pass does not close housing-on M1; an FDI31 witness does not close FDI21; saved replay does not authorize motion.

### 7. Resume batch only on a reasoned basis

Use the measured cost evidence and accepted setup to choose the next bounded comparison. Preserve all failures and NotRun outcomes; save/reopen the completed record before wider Studio work.

No implementation or runtime action was performed while producing this report. The next action remains a decision for the operator.

DENTOBOT | Decision report | 2026-09-23 | Research simulation only | 20

# 17. Exact artifacts and reproducibility identifiers

### Original Sep-19 FDI31

/home/light-tarun/dentobot/data/Slicer_Saved/SampleStudy1/FDI31/dentobot-case-sep19-step6.dentocase

SHA-256: dfe492076674d9fa34c8eb9e010ff6a69e022438b06a081ea3fc4c6a1fc981ab

### Sep-22 FDI31

/home/light-tarun/dentobot/data/Slicer_Saved/SampleStudy1/FDI31/dentobot-case-sep22-step6.dentocase

SHA-256: eb48a805c81578bafcc8ca72663b6f8a98b1f9721c7f9e680d44b458558e7adb

### Two-target headless-verified input

/home/light-tarun/dentobot/data/Slicer_Saved/SampleStudy1/FDI21-31-headless-verified-sep22-step6a.dentocase

SHA-256: c16e0406b589de1cb2144628b38a26100157458d48b5edb9c56ad4f8792d1c1d

### Current-profile Home source

/home/light-tarun/dentobot/data/dentobot-runs/step65-three-planner-fdi21-31-20260923/fdi21-r3/FDI21-current-profile-home. dentocase

SHA-256: d6da41b87c63549bdcffef06ce1df779f3ed396fe304ed826010147dfed0510c

### Latest completed-trial checkpoint

/home/light-tarun/dentobot/data/dentobot-runs/step65-three-planner-fdi21-31-20260923/fdi21-r6/checkpoint.json

SHA-256: 49115ceaf8d3cfcf8e72444a81d6ca74e694d41587dfe97e9805be3fdc7883b1

### Timing events

/home/light-tarun/dentobot/data/dentobot-runs/step65-three-planner-fdi21-31-20260923/fdi21-r6/timeline.jsonl

SHA-256: 9502a7eedc5f2937351ac7ecf7447615d5dc6b80b5e79edb60869ff20dc75ccf

### Invalid capture manifest

/home/light-tarun/dentobot/data/dentobot-runs/step65-three-planner-fdi21-31-20260923/fdi21-r6-collision-recapture-r3/mani fest.json

SHA-256: 9ea57c679025ce82188aeb97a6dcac6e9689978db3aa535514d476e4bad1d95a

The hashes above are computed during report preparation. A checkpoint is not a completed case. Source case and run outputs are preserved separately.

DENTOBOT | Decision report | 2026-09-23 | Research simulation only | 21

# 18. Retained rejected state and identity

The following state was retained by the offline capture manifest from the r6 checkpoint. The manifest’s tooth geometry is incorrect; the numeric robot vector and native message are retained evidence, not validation of its images.

Joint | Recorded SI value
link-1_Revolute-1 | 0.042047916865283974
link-2_Slider-2 | 0.00036656668634758036
link-3_Revolute-3 | 3.4388198100123732
link-4_Slider-4 | 0.013680814721990668
link-5_Revolute-5 | 0.4085713105355186

Revolute joints use radians; slider joints use metres. J6 is external spindle action, not a planned positioning DOF.

### Native message

Full-chain guard rejected waypoint 459 (drilling): Task guard rejected drilling sequence 460: MoveIt detected a non-approved collision at interpolated sample 1/1. (dentobot_target_tooth_2.25.156727832881888777359082987559036393993 ↔ pneumatic_spindle-Copy)

### Checkpoint context

Selected candidate: 6; workspace clearance sample: 198. First-invalid TCP world RAS approximately [-95.45838257548839, -37.504953467682284, 60.796333221604584] mm. Nearest points and native contact depth are unavailable in the retained r6 record.

### Base fingerprint

230ce2cda5723fbc41fadfd9c1f0f887710b29a444cbf73bee4daddaa394e47c

### Source boundaries

The source case audit has the upper tooth correctly fixed. The r6 live acknowledgement has a different audit event identity. Correct source geometry is necessary but not sufficient to assert exact live-scene equivalence. That comparison belongs to the next bounded evidence gate.

DENTOBOT | Decision report | 2026-09-23 | Research simulation only | 22

# 19. Source index and evidence hierarchy

### S1 Canonical execution contract

/home/light-tarun/dentobot/docs/diagnostics/FDI31_GUI_PLANNER_P0_PLAN_2026-09-21.md

### S2 Current run history and source findings

/home/light-tarun/dentobot/docs/logbook/2026-09-23.md

### S3 Prior multi-target and manual results

/home/light-tarun/dentobot/docs/logbook/2026-09-22.md

### S4 Pending state and owner mapping

/home/light-tarun/dentobot/docs/backlog.md

### S5 Task contracts

/home/light-tarun/dentobot/docs/TASKS.md

### S6 Milestone / Studio design

/home/light-tarun/dentobot/docs/DEVELOPMENT_PLAN.md

### S7 Technical decisions

/home/light-tarun/dentobot/docs/DECISIONS.md

### S8 Verification gates

/home/light-tarun/dentobot/docs/AGENTIC_VERIFICATION_PROTOCOL.md

### S9 Automation SOP

/home/light-tarun/dentobot/docs/diagnostics/STEP6_GUI_AUTOMATION_SOP_2026-09-23.md

### S10 Recapture implementation

/home/light-tarun/dentobot/ros2_ws/src/DentoBot/Testing/run_dentobot_step65_collision_recapture.py

### S11 Production scene preparation

/home/light-tarun/dentobot/ros2_ws/src/DentoBot/DENTOWorkflow/Resources/Python/dentobot_workflow/logic_robot_scene_s ync.py

### S12 Native evaluated state

/home/light-tarun/dentobot/ros2_ws/src/DentoBot/dentobot_moveit_config/src/collision_guard.cpp

### S13 Comparison automation

/home/light-tarun/dentobot/ros2_ws/src/DentoBot/Testing/run_dentobot_step65_three_planner_gui.py

Sections 1-5 synthesize the supplied chat plus S1-S7. Sections 6-9 use S2 and retained r3-r6 artifacts, with S10/S11 confirming the image-transform defect. Sections 10-16 distinguish engineering interpretation and proposed decisions from implemented behavior. The atlas captions name each image and its evidentiary limitation.

DENTOBOT | Decision report | 2026-09-23 | Research simulation only | 23

# 20. Screenshot atlas - interpretation rules

The following images are original user-provided screenshots or retained automated captures. They are embedded without reconstructing UI text or editing the scene. Each image is scaled to fit the page; zoom the PDF to inspect native screenshot detail.

Screenshots are chronological evidence, not instructions. Old successful results do not become current merely because they appear beside a new target. “Stale,” “NotRun,” partial path and guard warnings are retained in the interpretation.

The rejected offline collision images are included deliberately, marked INVALID FOR CONTACT INTERPRETATION. They document the evidence failure and must not be offered as proof of clearance or penetration.

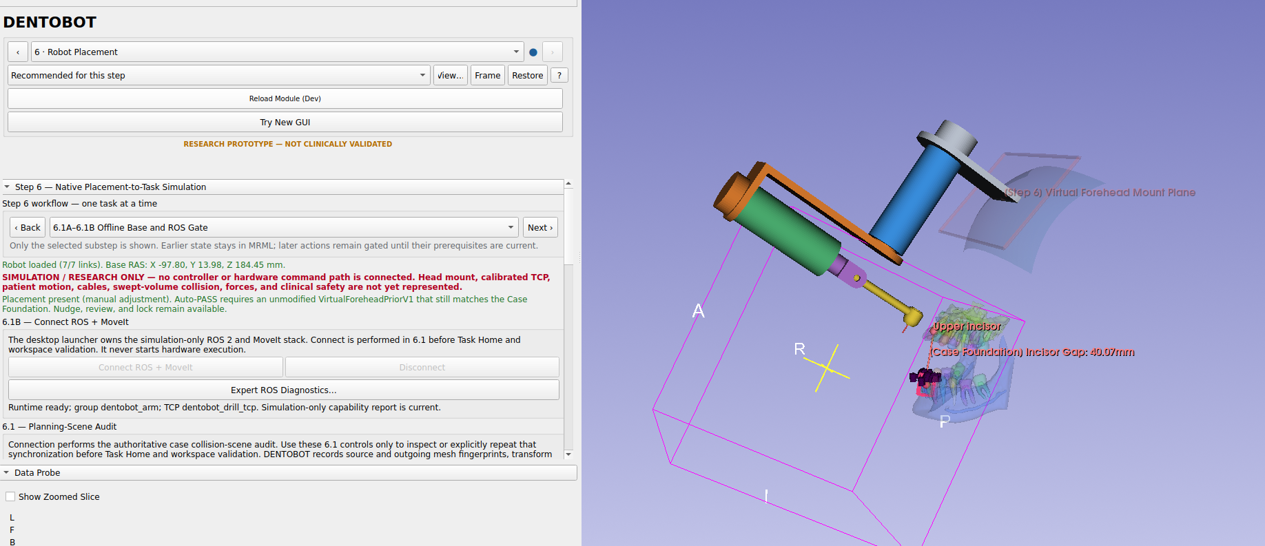
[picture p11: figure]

DENTOBOT | Decision report | 2026-09-23 | Research simulation only | 24

# Figure 01 | Early Step 6 ROS connection ambiguity

Operator reported both Connect and Disconnect grayed after case loading. The displayed Runtime ready message does not explain the gating state; this is UI/prerequisite evidence, not a planner outcome.

Source: /tmp/codex-clipboard-6f55b869-1db5-4e0d-a162-2b7d67a6620f.png

Image SHA-256: fec3669cd4932a3544e535a10574bea3e0ffc2d37588bbcf134c401466b146f7

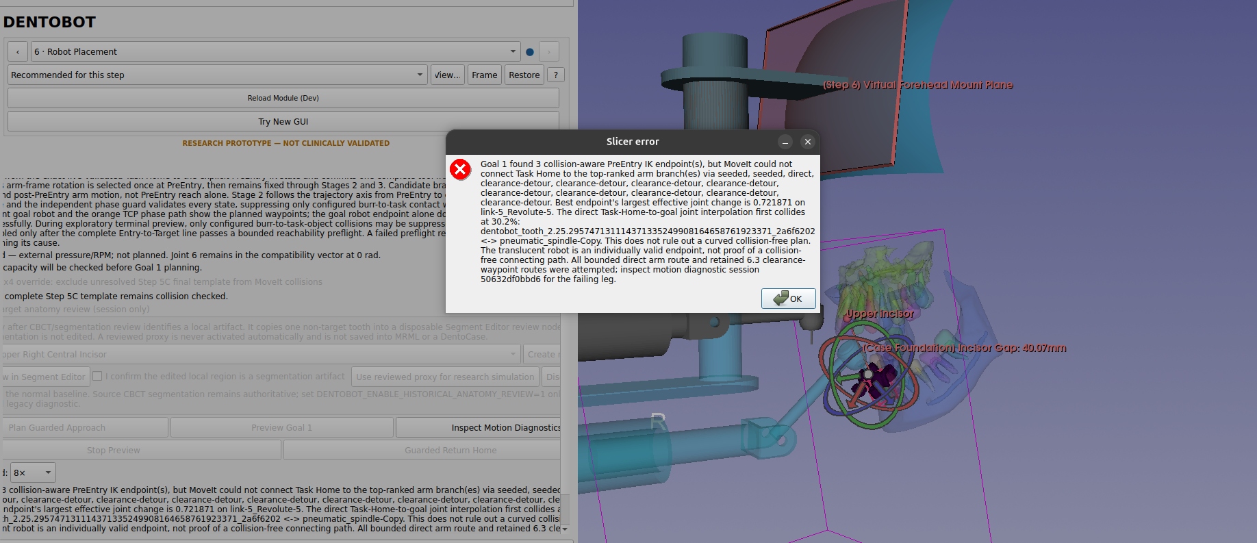
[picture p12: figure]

DENTOBOT | Decision report | 2026-09-23 | Research simulation only | 25

# Figure 02 | Sep-22 FDI31: endpoints exist, P1 connection fails

Three collision-aware PreEntry endpoints were found. Direct interpolation reports tooth versus spindle contact. The first Sep-22 attempt still used housing-on due to launch handoff; this is not proof Experiment A failed.

Source: /tmp/codex-clipboard-f0ef4418-c2c2-4b8d-bf54-348a7d58d4bf.png

Image SHA-256: 21e157c4b6e265c1f06449ce54e02cc95c2d7e9cd8f80f5a18077495251cf126

DENTOBOT | Decision report | 2026-09-23 | Research simulation only | 26

# Figure 03 | Diagnostic phase pass and route-activation gate

Stages show complete diagnostic output, but selecting a route reports Task Home not validated in the current session. Historical housing-off P1 evidence is M1-DIAG only; route selection does not restore current authorization.

Source: /tmp/codex-clipboard-41aa5537-4213-43a6-8f87-e531cec7edd4.png

Image SHA-256: fadc5eb7f834b8212f7c07a29fc33d332703371a27776a8cf6a5881b75c787bf

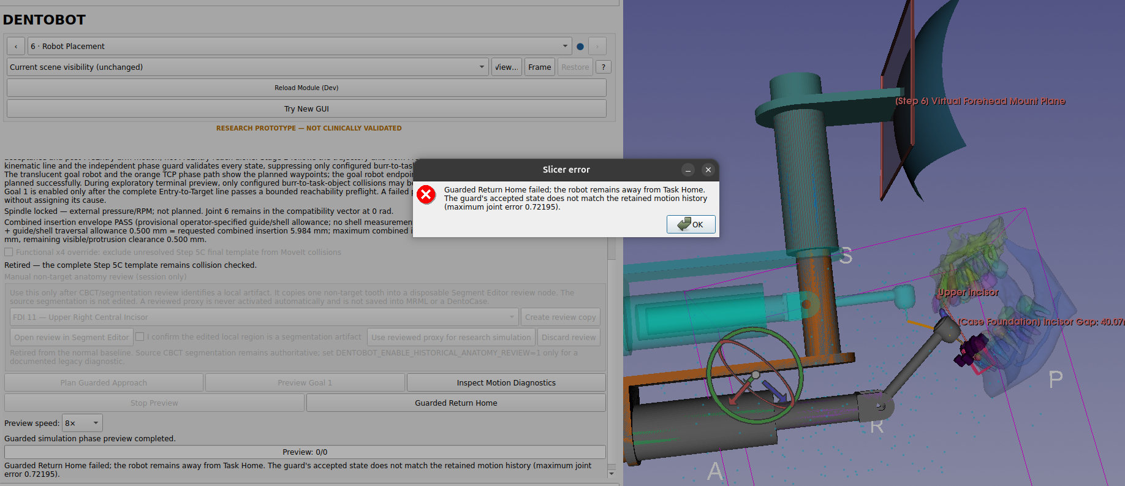
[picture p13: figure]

DENTOBOT | Decision report | 2026-09-23 | Research simulation only | 27

# Figure 04 | Guarded Return Home mismatch

Guard accepted state differs from retained motion history; maximum joint error 0.72195. This is a separate full-cycle state/history issue, not an explanation for all planning failures.

Source: /tmp/codex-clipboard-c8891b3b-878b-4172-b6e9-be8134be261c.png

Image SHA-256: 0436acccaa3198d51fc69fe4c92818786f9629702142a2ce120422f2a8d366fa

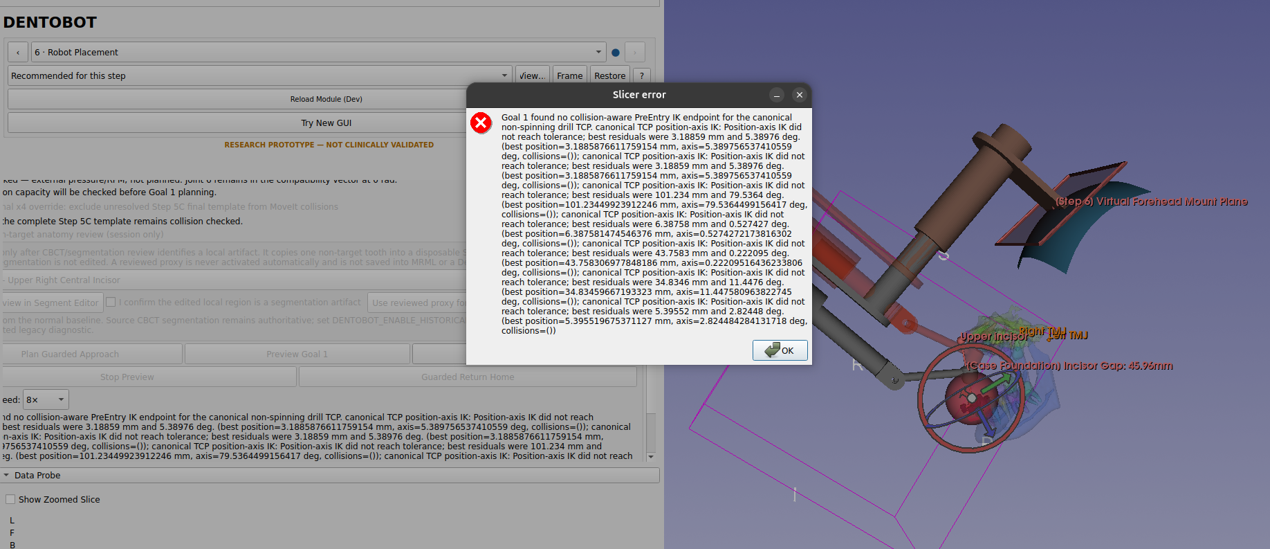
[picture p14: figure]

DENTOBOT | Decision report | 2026-09-23 | Research simulation only | 28

# Figure 05 | 45.96-mm opening: no tolerance-valid PreEntry IK

Reported position/axis residuals with empty collision lists. This particular failure concerns bounded IK convergence/reach at that setup, not a demonstrated spindle collision.

Source: /tmp/codex-clipboard-bce2e0f1-ac73-4392-9561-9af7573abad8.png

Image SHA-256: de6ee0346683d20d81e303edbfd87e2d66fa81d79b24152f666d5933488c60d7

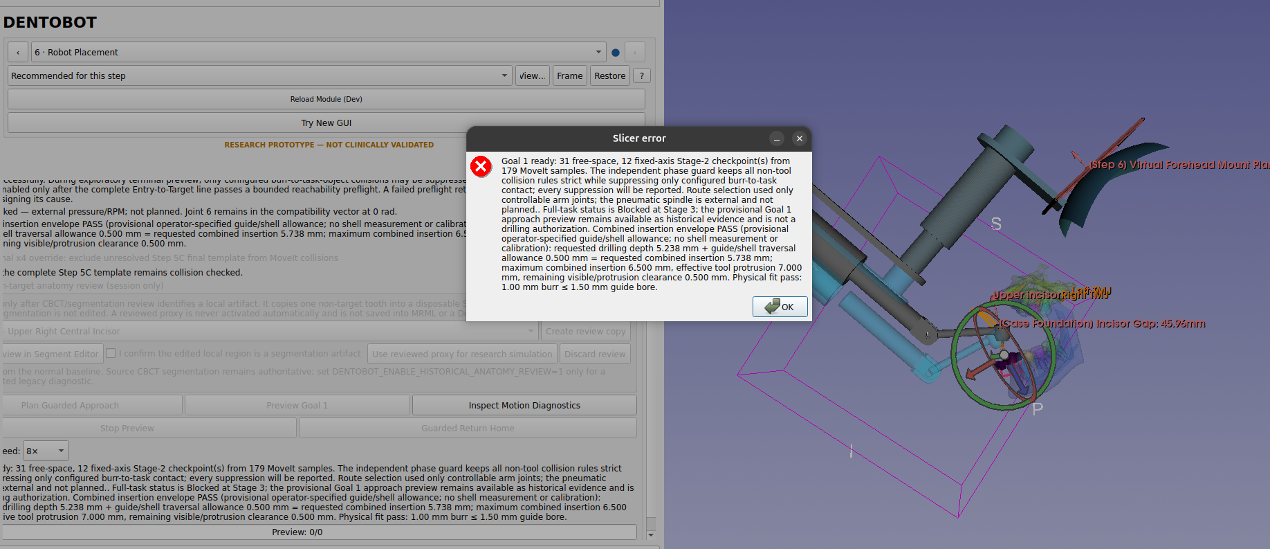
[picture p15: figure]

DENTOBOT | Decision report | 2026-09-23 | Research simulation only | 29

# Figure 06 | Same gap, changed Home: P1/P2 progress

Operator changed Home; approach was available while full task remained blocked at Stage 3. This supports separating approach connectivity from insertion acceptance.

Source: /tmp/codex-clipboard-8c72bf66-55ff-4c8f-afd8-56e7f5b85969.png

Image SHA-256: 0d3c5b738920bdc6f905dfb94167581f6b0ef20cd6b00c8654d6ded3a31c9c7a

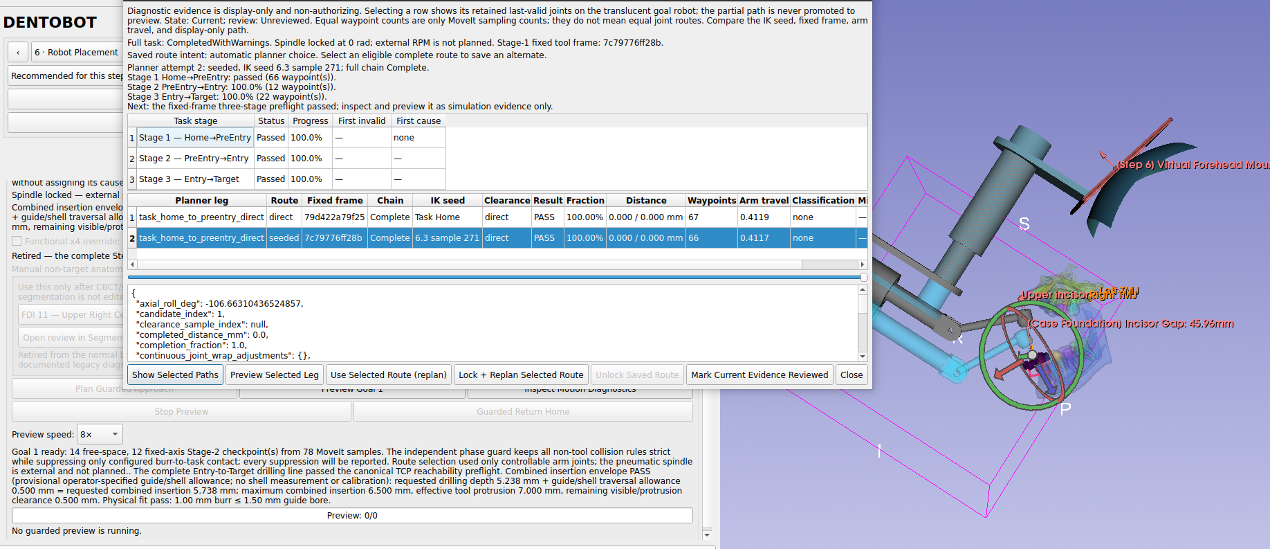
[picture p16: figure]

DENTOBOT | Decision report | 2026-09-23 | Research simulation only | 30

# Figure 07 | Operator FDI31 housing-on full-chain witness

Operator reported base position/orientation adjustment. The display shows 66/10/22 waypoints and CompletedWithWarnings. Meaningful alternate-setup evidence; not an independently reproduced fixed-input experiment.

Source: /tmp/codex-clipboard-5db5f538-f922-418b-b6dc-5c359af02909.png

Image SHA-256: f6e1e1b0a72bd131f62a7d42d4ba6b7551f913e93144f9446401f52b31219359

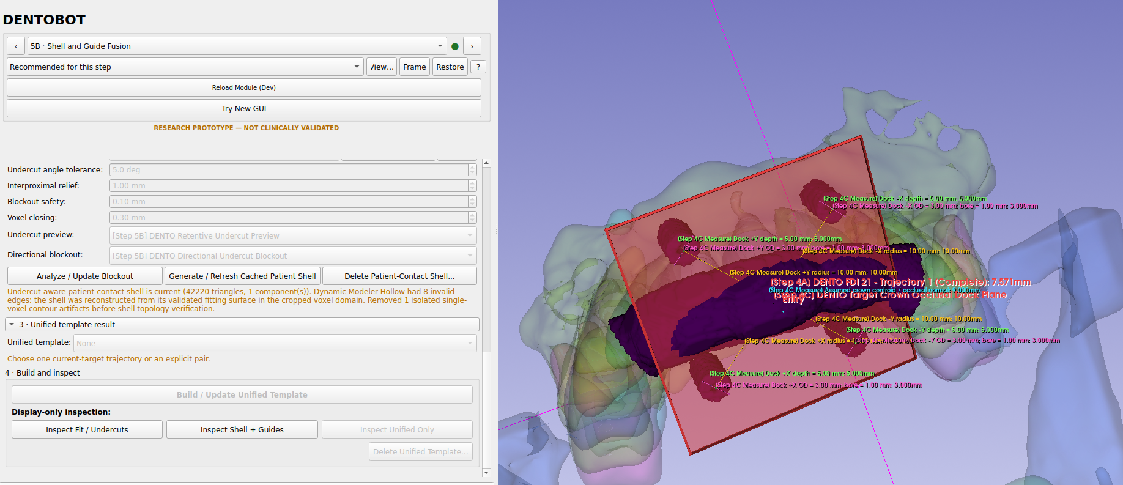
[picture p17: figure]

DENTOBOT | Decision report | 2026-09-23 | Research simulation only | 31

# Figure 08 | Second target blocked at Step 5B

Choose one current-target trajectory or explicit pair prevents unified template creation. This motivated selected-target lineage work.

Source: /tmp/codex-clipboard-ccd43578-a988-4765-a5ec-a8778000768b.png

Image SHA-256: 8220ff2303c6631c855b4f75f5bc25e837606d7e7f2634a3744ba3a15709b208

DENTOBOT | Decision report | 2026-09-23 | Research simulation only | 32

# Figure 09 | Step 5C current-frame dock failure

Other geometric checks pass while single current-frame target dock fails. A template’s geometric existence is distinct from its current provenance.

Source: /tmp/codex-clipboard-320076a0-a823-4483-bd0e-6cdc4de79d07.png

Image SHA-256: 12d2b747c6baddcf3699e44d6f858d6ffda58013a52921bea522c76d3a78f502

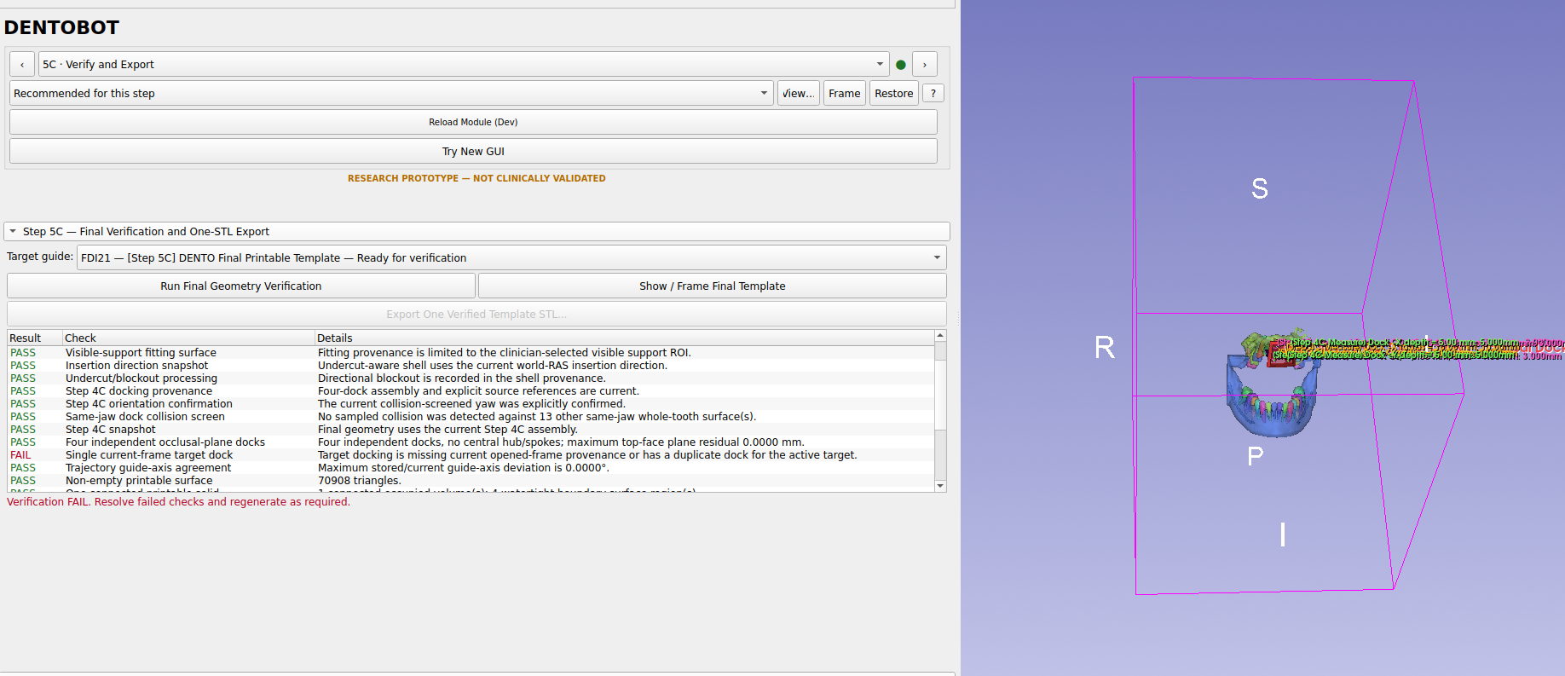
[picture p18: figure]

DENTOBOT | Decision report | 2026-09-23 | Research simulation only | 33

# Figure 10 | Selector added, verification still failing

FDI21 Ready for verification did not imply successful verification. The operator correctly challenged a UI change that did not resolve the underlying lineage check.

Source: /tmp/codex-clipboard-72314d4f-19b2-4628-9c00-4bc4eeebd25d.png

Image SHA-256: ee76e9f28342acbadc17a92ab51955d62597f965736b2d82264e0c564e75b0c6

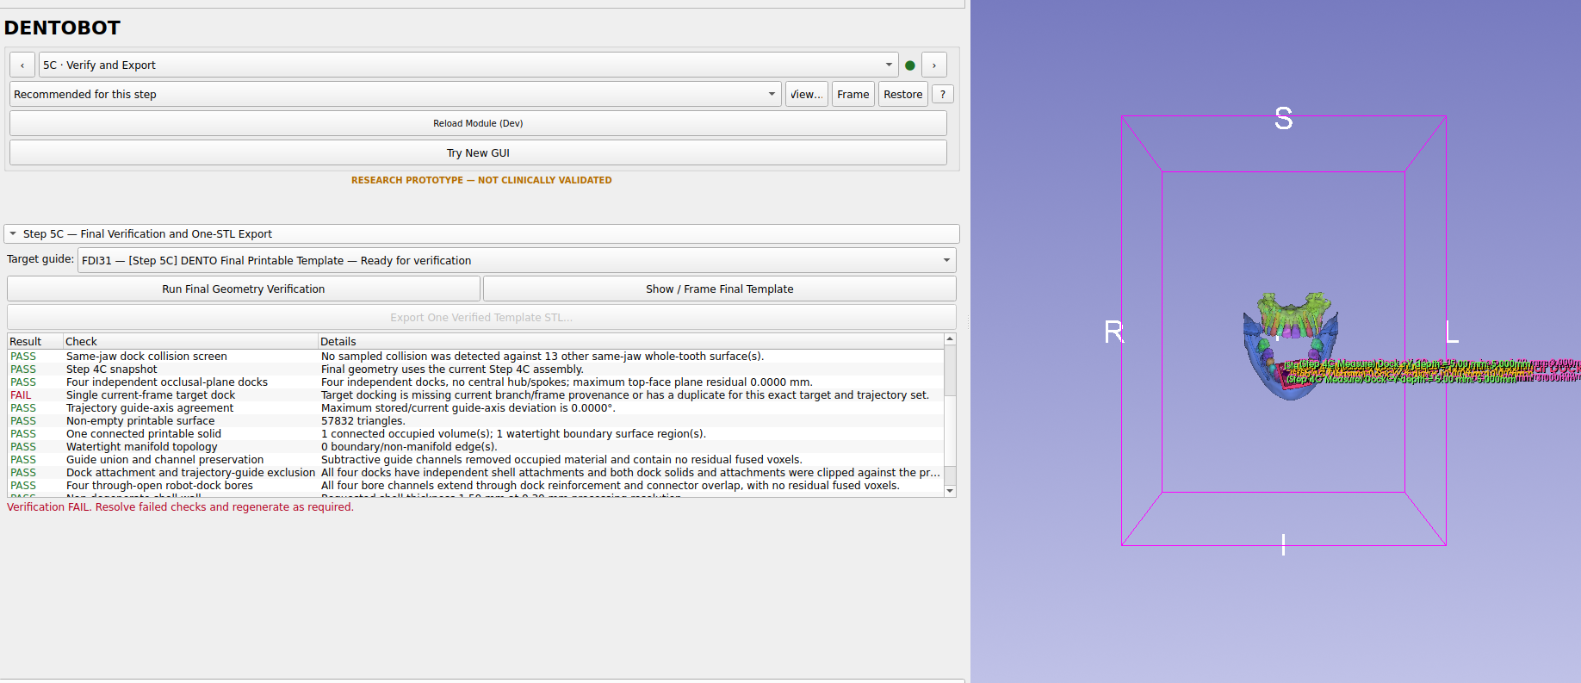
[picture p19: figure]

DENTOBOT | Decision report | 2026-09-23 | Research simulation only | 34

# Figure 11 | Rebuilt FDI31 still fails dock provenance

Failure text references exact target and trajectory set. Regeneration alone did not establish correct cross-target ownership.

Source: /tmp/codex-clipboard-c23214b9-a574-47eb-8479-45c23fe3eaea.png

Image SHA-256: da27a569f974e735ba80b448877f1c40d799de66d84f11b32818a692a165cb04

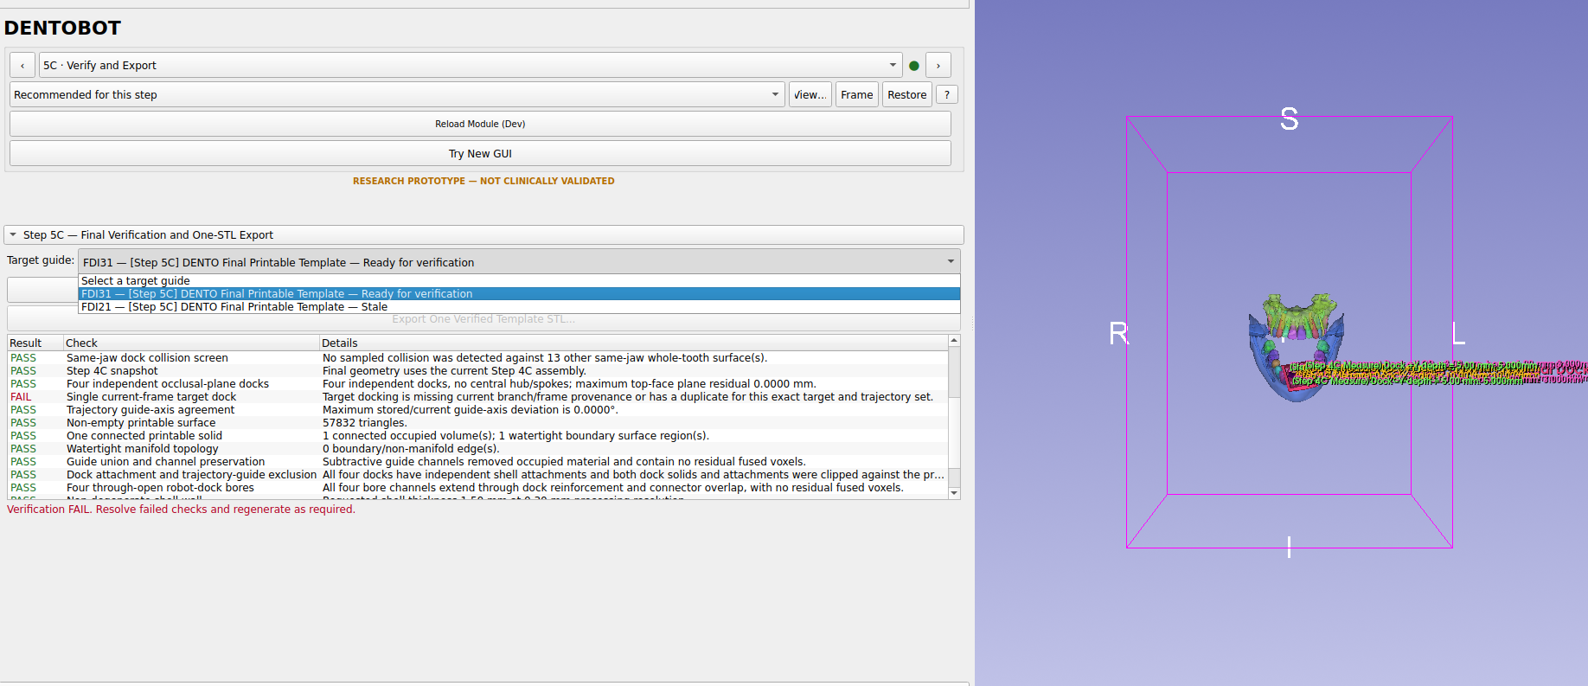
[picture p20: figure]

DENTOBOT | Decision report | 2026-09-23 | Research simulation only | 35

# Figure 12 | Alternating guides exposes cross-target staleness

FDI31 Ready and FDI21 Stale in one selector. This is the coexistence problem the PreparedBranch work needed to address.

Source: /tmp/codex-clipboard-0e7602b5-2a77-4899-98fb-57db92b18d86.png

Image SHA-256: 9d7cd74dea111f1a2a29fc0e875ed96055718638bcc5e9ade22bc1d8349ea13c

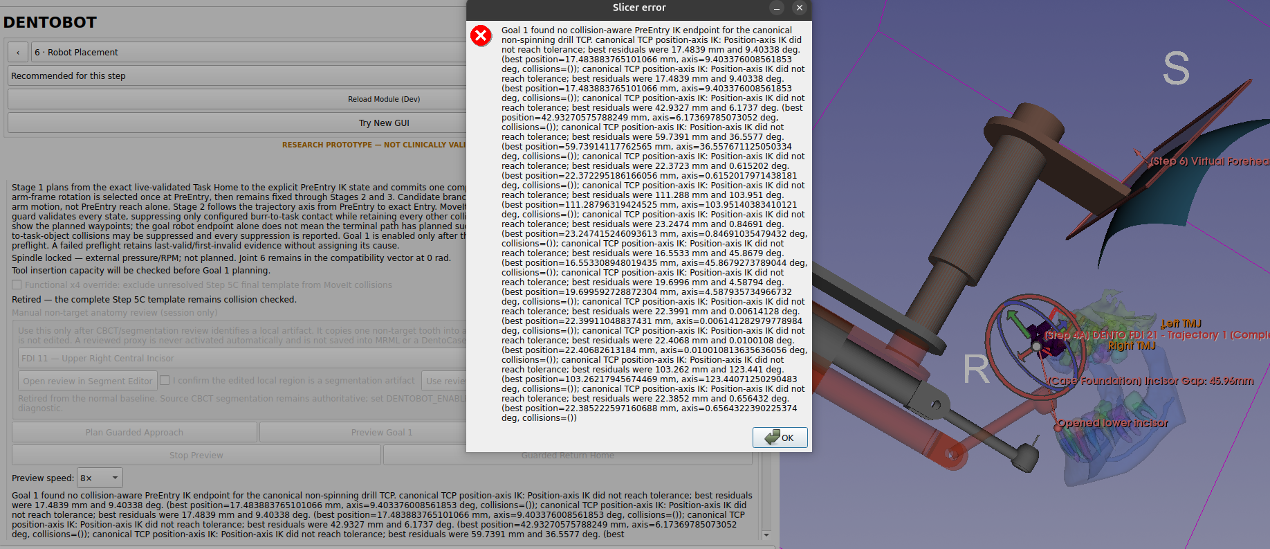
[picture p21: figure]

DENTOBOT | Decision report | 2026-09-23 | Research simulation only | 36

# Figure 13 | FDI21 planner reports no valid PreEntry endpoint

A fresh error shows position-axis IK residuals. It must not be combined with a stale complete-chain report to claim a current success.

Source: /tmp/codex-clipboard-1e7f43f7-05f9-495c-b3bc-6ab41a17f260.png

Image SHA-256: 540b53552e77ae58dada386148337306ce27a910cb4887c23bc825d05d159463

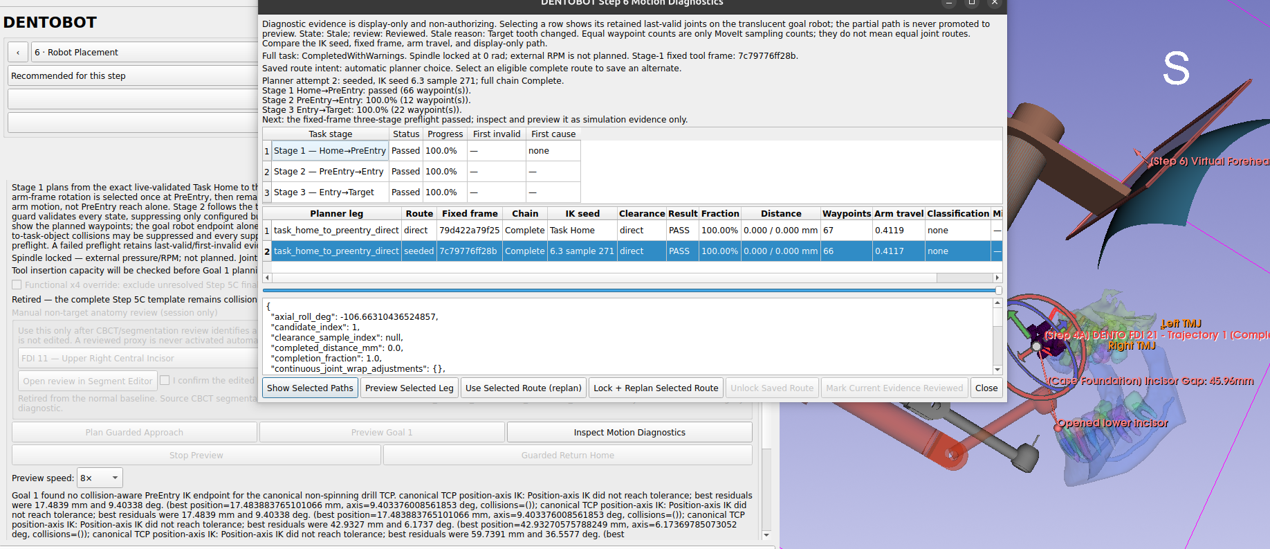
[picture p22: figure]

DENTOBOT | Decision report | 2026-09-23 | Research simulation only | 37

# Figure 14 | Legacy complete diagnostics explicitly stale

Top text: State Stale; reason Target tooth changed. The old 66/10/22 result is not the new FDI21 run.

Source: /tmp/codex-clipboard-f50d2446-be6c-461b-a05b-8a2eb8eacee6.png

Image SHA-256: 3cd4bdb94e81896704e4282363d016039d6de43641c8877ae073cbee212b4bb0

DENTOBOT | Decision report | 2026-09-23 | Research simulation only | 38

# Figure 15 | Step 6.4 snapshot confirmation disabled

Operator had advanced through prerequisites but could not confirm. A disabled button requires prerequisite attribution, not a bypass.

Source: /tmp/codex-clipboard-1c95e5e1-42bd-4d7e-b0f4-dd43a382714c.png

Image SHA-256: 23788000f6c0ec623762c55a89352de625a60c71c480200ce4e5c4db85a5e3ff

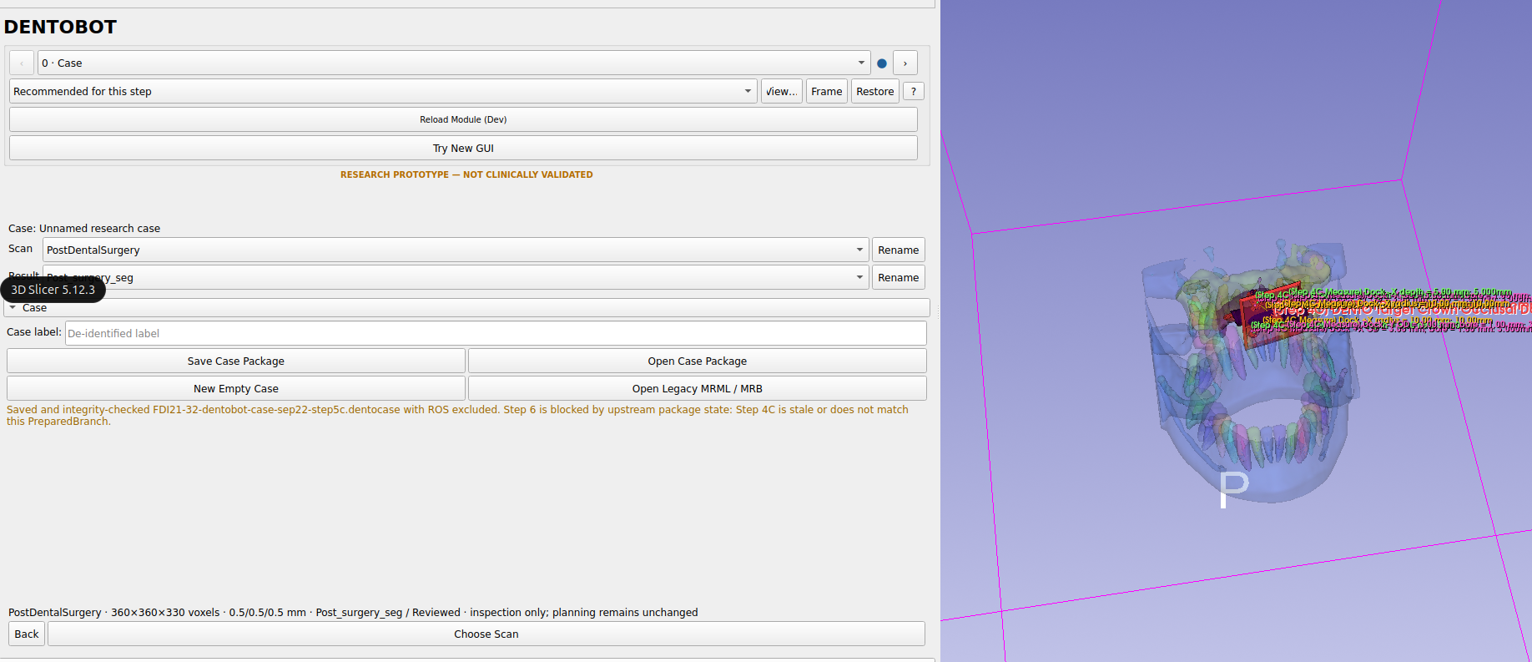
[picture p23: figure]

DENTOBOT | Decision report | 2026-09-23 | Research simulation only | 39

# Figure 16 | Case save preserves upstream branch mismatch

Saved and integrity-checked package explicitly reports Step 4C stale/mismatched to PreparedBranch. Archive integrity and workflow eligibility are distinct.

Source: /tmp/codex-clipboard-6d393a28-be84-4281-a320-4b0ce49b3ef2.png

Image SHA-256: c968499af9d7ab56abfdfb498c26327f905772ef4bdf68b885a45d561bf8e311

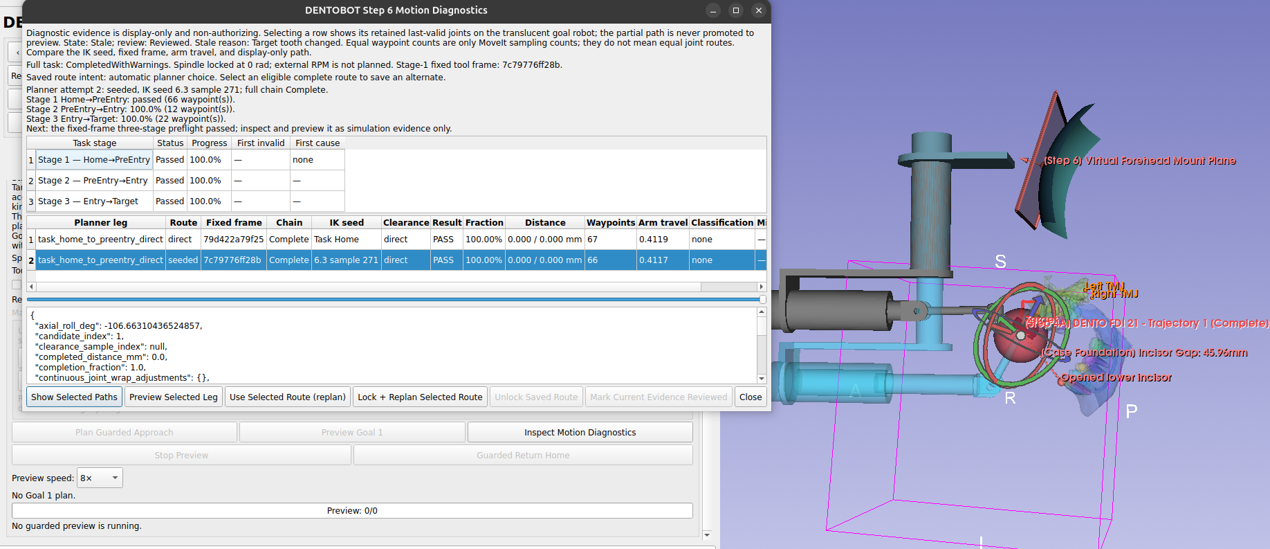
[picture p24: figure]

DENTOBOT | Decision report | 2026-09-23 | Research simulation only | 40

# Figure 17 | Claimed FDI21 pass with stale evidence caveat

Operator reported manual base adjustment and success; displayed diagnostics still say target changed and underlying panel says No Goal 1 plan. Preserve the report, but this image alone does not certify fresh FDI21 full-chain acceptance.

Source: /tmp/codex-clipboard-c248b0dd-453c-415a-a74d-e27142688612.png

Image SHA-256: 5e1dd217b05e9d5302d712cfad3ccab97cedcc4a23bded7fdcbd31fc7017af6f

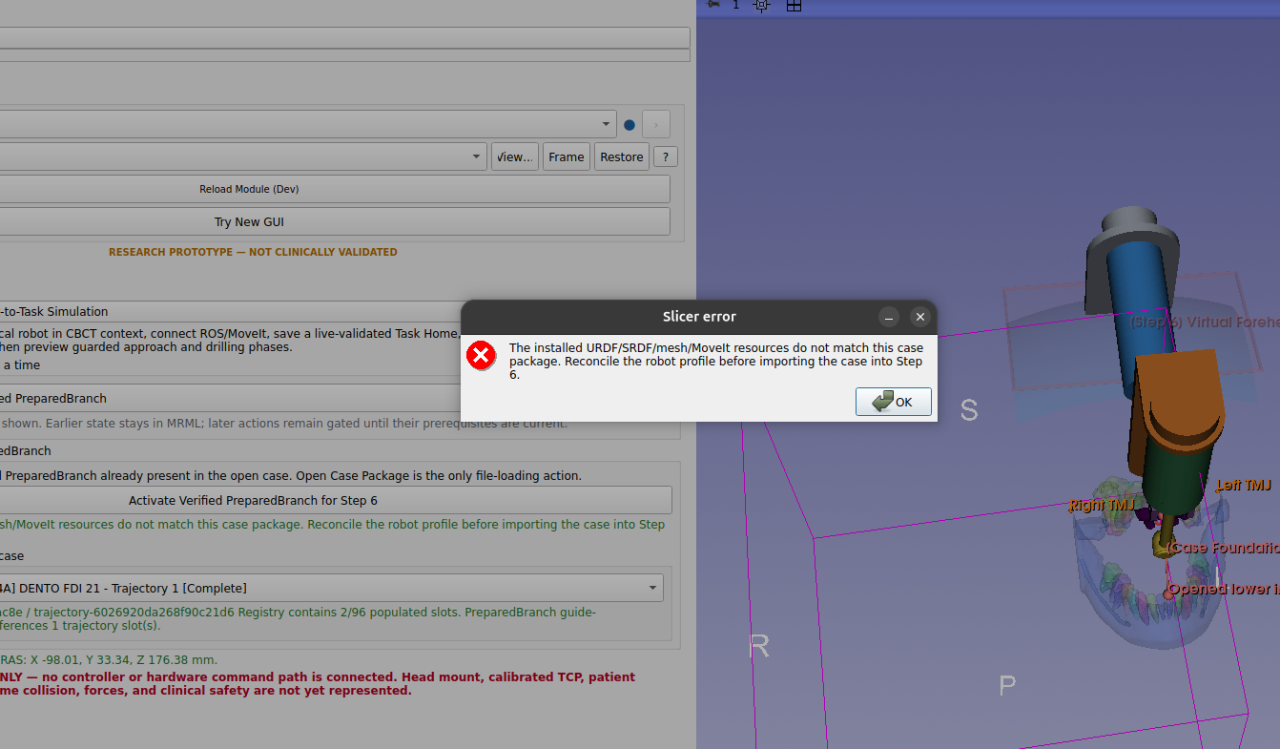
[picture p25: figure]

DENTOBOT | Decision report | 2026-09-23 | Research simulation only | 41

# Figure 18 | Robot-profile compatibility gate

Installed URDF/SRDF/mesh/MoveIt resources do not match the saved case. This prevents activation before planning and is not planner-performance evidence.

Source: /tmp/codex-clipboard-831a50d2-8a3f-42b5-bb73-04aae20251dc.png

Image SHA-256: 41935717fd8e5cc42d5ea1f10e4df1079058a1dcc6ae749f551c4f2f537cf5b2

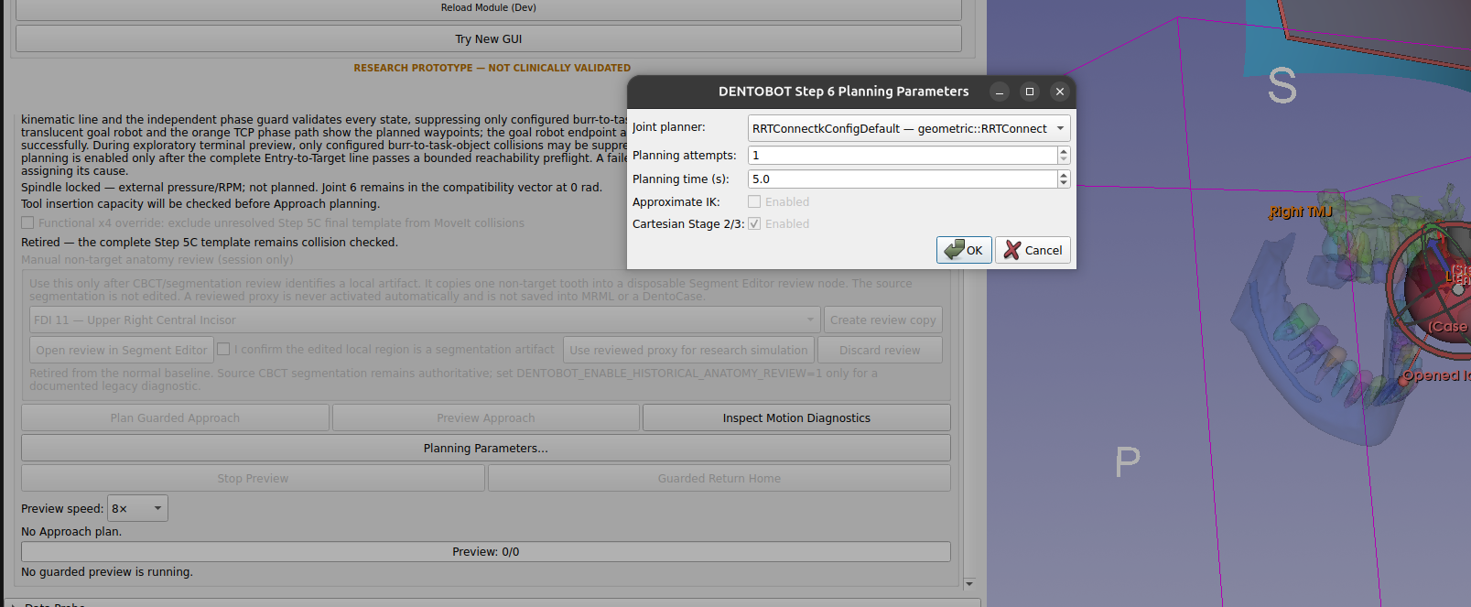
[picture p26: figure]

DENTOBOT | Decision report | 2026-09-23 | Research simulation only | 42

# Figure 19 | Planning controls and locked features

Initial shared parameters: RRTConnect, one attempt, 5 s; approximate IK disabled and Cartesian enabled but locked. Operator requested RRT*, tips and explanations.

Source: /tmp/codex-clipboard-07505912-ea0f-417d-9636-b3b115a86c5c.png

Image SHA-256: d02968bee7e4258591ed74f10bd68efa64efdd20cd56e4c9535a03fbcf35ff9f

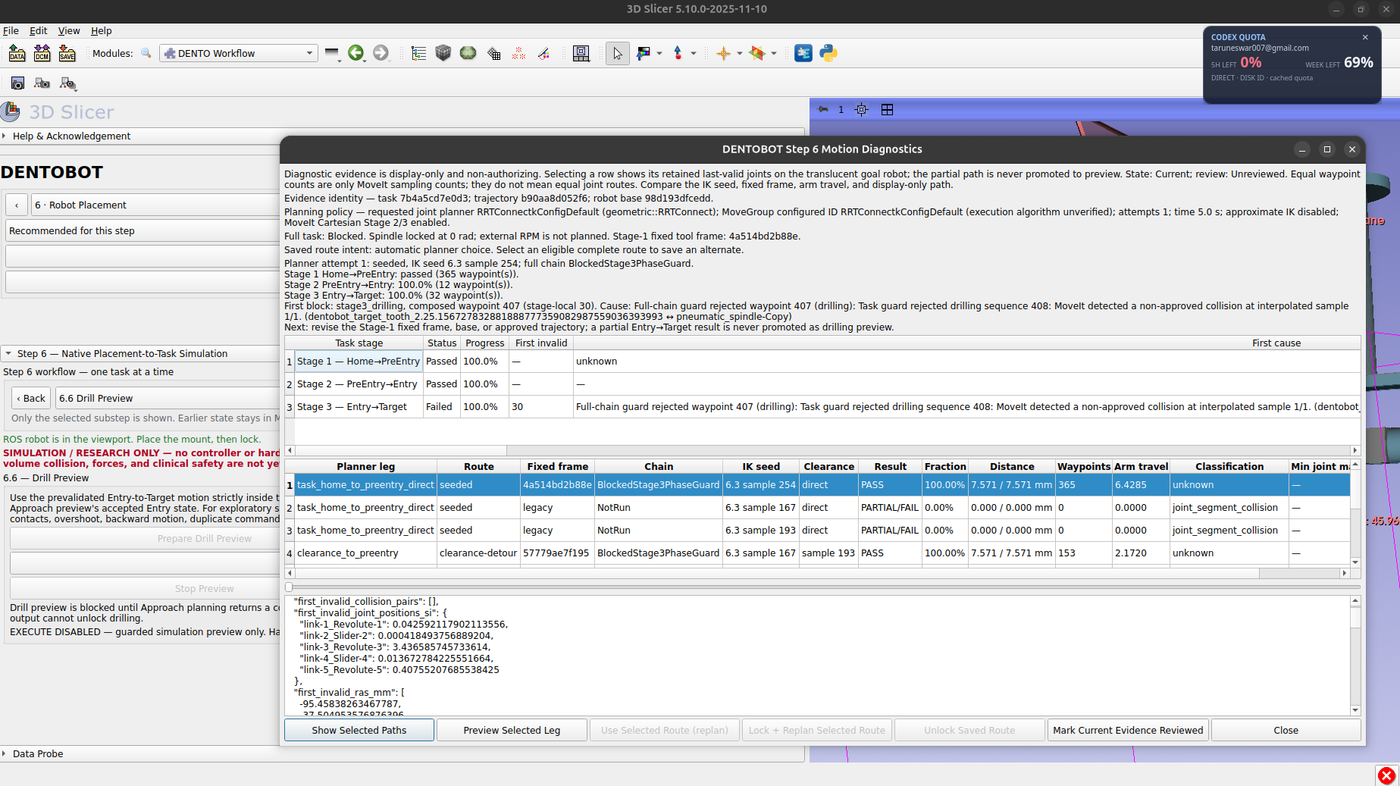
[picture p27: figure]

DENTOBOT | Decision report | 2026-09-23 | Research simulation only | 43

# Figure 20 | Configured planner and Stage-3 guard failure

Current diagnostic shows configured RRTConnect, P1/P2 pass, Stage-3 non-approved tooth/spindle contact. Configured ID explicitly does not prove executed algorithm.

Source: /tmp/codex-clipboard-93734918-46ad-415f-bf2f-b5e9a01e3a52.png

Image SHA-256: 6f49b0dc3f633ccc42d56bd7793116b983af9afc5f6cdfd28223116758cd5c75

DENTOBOT | Decision report | 2026-09-23 | Research simulation only | 44

# Figure 21 | Alternative candidate rows retain failures

Direct and clearance candidate rows have mixed results and full-chain blocks. A route row PASS is not necessarily complete task acceptance.

Source: /tmp/codex-clipboard-d4bcb761-84c6-4e49-802c-546733908fd1.png

Image SHA-256: 09af702e2c910af4756bdb18aee64465239a9845d08024c864198574bb15f495

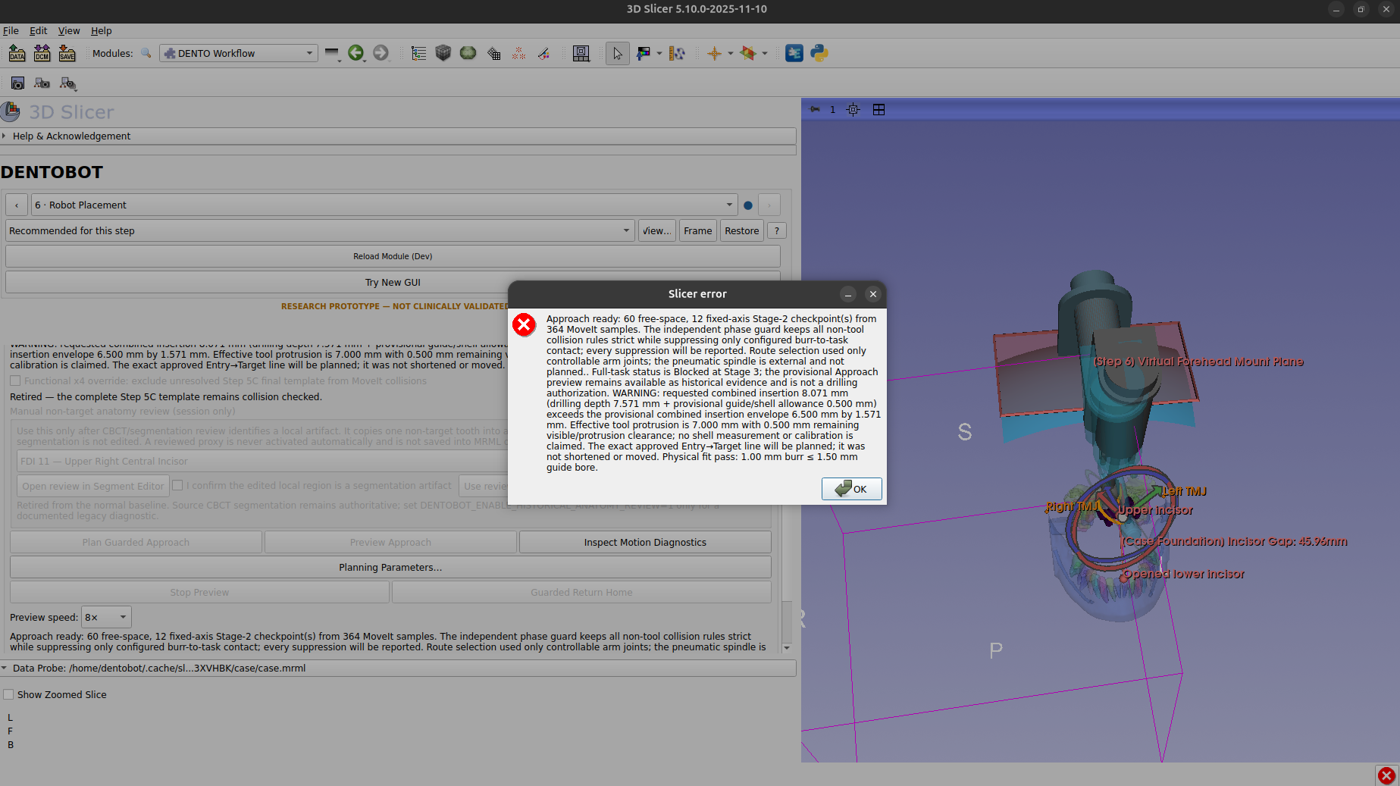
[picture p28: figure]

DENTOBOT | Decision report | 2026-09-23 | Research simulation only | 45

# Figure 22 | Detailed result dialog and insertion warning

Approach ready while Stage 3 blocked; 8.071-mm combined insertion versus 6.5-mm provisional envelope. This message must remain recoverable after closing.

Source: /tmp/codex-clipboard-3bfda34a-24e7-4429-96cb-0a8824c0ee9d.png

Image SHA-256: 1926ca4fb585bdcff7439438767ca34c893b69b2750ac66c35e2892dd52554bf

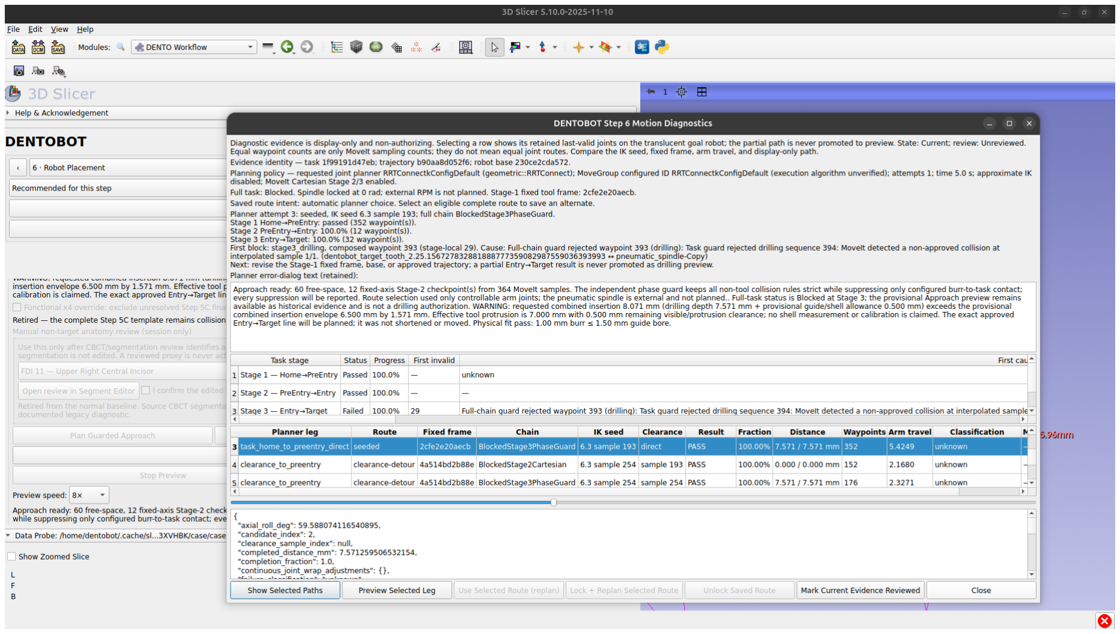
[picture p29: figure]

DENTOBOT | Decision report | 2026-09-23 | Research simulation only | 46

# Figure 23 | Operator-confirmed retained error text

Motion Diagnostics includes the prior dialog text; user confirmed hover tips too. This is acceptance evidence for observability, not for the blocked drilling task.

Source: /tmp/codex-clipboard-30dcbdc4-c95e-48a2-a213-eca10f1bb055.png

Image SHA-256: c94728a52354577f7d39c11cecef7bd3a3b87f89c00f0755853fea0bcd12293c

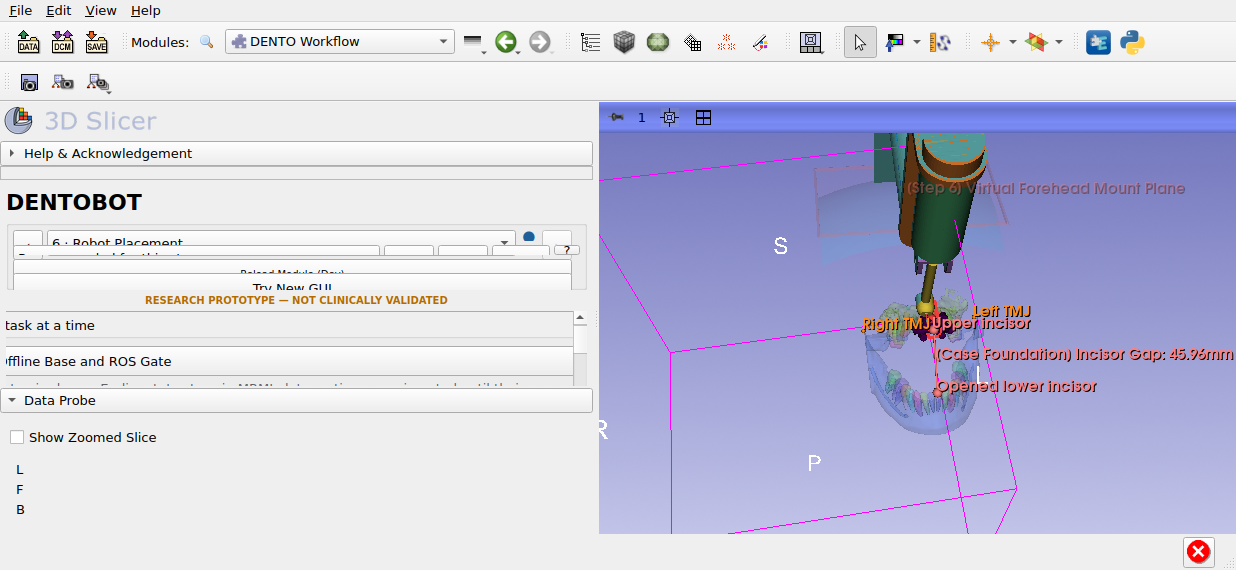
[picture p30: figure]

DENTOBOT | Decision report | 2026-09-23 | Research simulation only | 47

# Figure 24 | r6 automated base/runtime context

Retained setup image. View is tight; exact pose comes from numerical records, not visual estimation.

Source: /home/light-tarun/dentobot/data/dentobot-runs/step65-three-planner-fdi21-31-20260923/fdi21-r6/FDI21-base-runtim e.png

Image SHA-256: 2371b9158485df822f101720786685ab57cf2fa72607cb5b00fa317d0cf4ace2

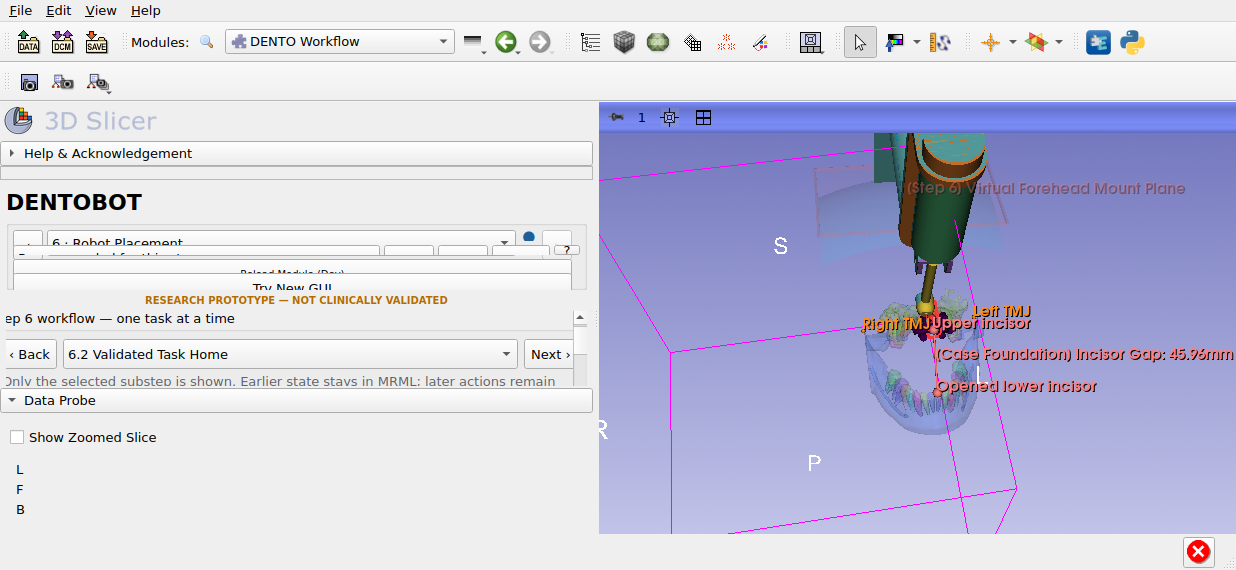
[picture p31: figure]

DENTOBOT | Decision report | 2026-09-23 | Research simulation only | 48

# Figure 25 | r6 automated Task Home evidence

Step 6.2 context retained separately after the earlier incorrect-substep capture. It does not substitute for the exact Home vector/fingerprint.

Source: /home/light-tarun/dentobot/data/dentobot-runs/step65-three-planner-fdi21-31-20260923/fdi21-r6/FDI21-task-home.p ng

Image SHA-256: 6f2765a714743cc352ff03b5d677a29ad4ef07a37cdc4f1bda34d215e11359b3

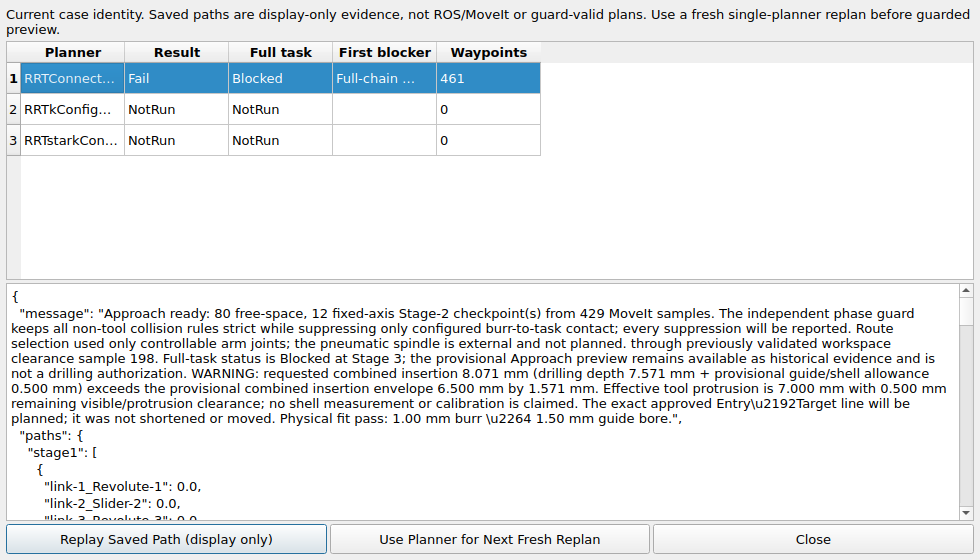
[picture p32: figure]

DENTOBOT | Decision report | 2026-09-23 | Research simulation only | 49

# Figure 26 | r6 completed RRTConnect checkpoint

Latest completed trial. Stage-3 collision persists; remaining planners do not have completed comparable outcomes.

Source: /home/light-tarun/dentobot/data/dentobot-runs/step65-three-planner-fdi21-31-20260923/fdi21-r6/FDI21-rrtconnect-d iagnostic.png

Image SHA-256: aa4591b3f09093cfaeeca22e90ec2ce2fc9604e2ff160b361aed82d678d33bf4

DENTOBOT | Decision report | 2026-09-23 | Research simulation only | 50

# Figure 27 | INVALID contact evidence - inferior

INVALID FOR CONTACT INTERPRETATION. Operator rejected this offline reconstruction. The script incorrectly applied the lower-jaw transform to fixed upper FDI21, producing separated model bounds. Included only to document the failed evidence path. It proves neither clearance nor native collision depth.

Source: /home/light-tarun/dentobot/data/dentobot-runs/step65-three-planner-fdi21-31-20260923/fdi21-r6-collision-recapture -r3/FDI21-first-invalid-inferior.png

Image SHA-256: b9647097449be695a8b692b3922a1dda45b1695903d4287c9fc4217ed1d1ec39

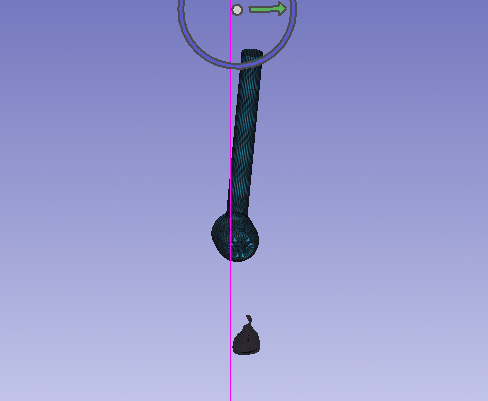
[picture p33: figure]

DENTOBOT | Decision report | 2026-09-23 | Research simulation only | 51

# Figure 28 | INVALID contact evidence - apical

INVALID FOR CONTACT INTERPRETATION. Operator rejected this offline reconstruction. The script incorrectly applied the lower-jaw transform to fixed upper FDI21, producing separated model bounds. Included only to document the failed evidence path. It proves neither clearance nor native collision depth.

Source: /home/light-tarun/dentobot/data/dentobot-runs/step65-three-planner-fdi21-31-20260923/fdi21-r6-collision-recapture -r3/FDI21-first-invalid-apical.png

Image SHA-256: 9197fce56c44aca7426885b005d0a9533286ded4e6b6f67fce1037aecf9bb0d0

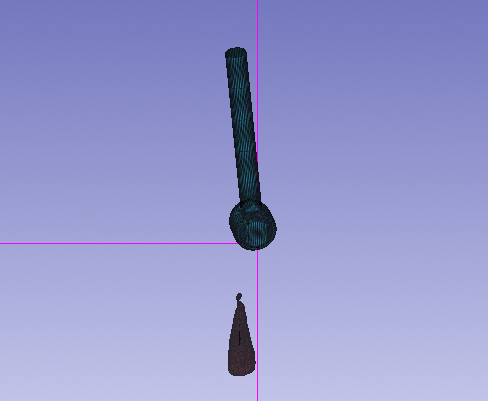
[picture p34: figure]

DENTOBOT | Decision report | 2026-09-23 | Research simulation only | 52

# Figure 29 | INVALID contact evidence - oblique

INVALID FOR CONTACT INTERPRETATION. Operator rejected this offline reconstruction. The script incorrectly applied the lower-jaw transform to fixed upper FDI21, producing separated model bounds. Included only to document the failed evidence path. It proves neither clearance nor native collision depth.

Source: /home/light-tarun/dentobot/data/dentobot-runs/step65-three-planner-fdi21-31-20260923/fdi21-r6-collision-recapture -r3/FDI21-first-invalid-oblique.png

Image SHA-256: 9e7ec373bbdc3e8b6790c5325f556ab850d8122e91f860b254773f6d09622aba

DENTOBOT | Decision report | 2026-09-23 | Research simulation only | 53

# Appendix A. Detailed recorded execution chronology

Selected Sep-23 logbook excerpt, preserved as historical execution evidence. Later statements in this report supersede older “next” proposals in this excerpt. It is not a new execution checklist. Dates, outcomes and command claims belong to the original entries; they were not rerun during PDF preparation.

FDI32. The exact input is
data/Slicer_Saved/SampleStudy1/FDI21-31-headless-verified-sep22-step6a.dentocase (SHA-256 c16e0406b589de1cb2144628b38a26100157458d48b5edb9c56ad4f8792d1c1d). Read-only lineage inspection confirms an FDI21 branch
guide-fe8080de25e7eb57622d and an FDI31 branch
guide-5c0da27697aceceb8f14; FDI21 is selected at save. The preceding
FDI32 missing-input stop is resolved by this correction. Runtime execution still awaits the protocol's explicit approval of the bounded serialized plan.

Runtime approval and attempt 1: Tarun approved the two-target serialized simulation-only run. The first FDI21 headless Slicer process loaded the input
but failed before planning with Load and place the local MRML robot before
connecting ROS/MoveIt; startup also reported the ROS2 module unregistered.
Evidence: data/dentobot-runs/step65-three-planner-fdi21-31-20260923/fdi21/failure.json. This was an automation setup failure, not a planner failure. No output case or comparison screenshot was produced. The runner was corrected to call its
existing facade.loadRobot() step; the next bounded retry will use the
installed ROS2 module paths and the simulation stack handoff script. Failure count for this setup blocker: 1.

Runtime attempt 2 and stop: The corrected handoff launched canonical housing-on dentobot.urdf, reached simulation readiness, loaded the local robot and synchronized the collision scene. It then stopped before planning: validate saved Task Home: Task Home belongs to different robot resources. Evidence:
data/dentobot-runs/step65-three-planner-fdi21-31-20260923/fdi21-r2/failure.json and the handoff output/stack log. Read-only comparison shows the saved case profiles moveit/config/ompl_planning.yaml at SHA 10f6f69a2f40f047b64430d1f408ecec0350ee29cafc27a9758d07821b16c355, while the checked-in current YAML SHA is 9acb46e12a30dcf198d2fe415f10446b8f340fe57b9051de7a9ad91cbab5e7b3. applyTaskHome() correctly rejects the stale robot-resource identity. The stack handoff cleaned up. No planner trial, output DentoCase, or screenshot was produced; FDI31 was not started. This is a new substantive profile/Home blocker, not a planner outcome. The test will not auto-save a replacement Home. Two runtime attempts total; further runtime is paused pending operator direction on explicit current-profile Home recapture and case save.

Operator-approved current-profile recapture / attempt 3: Tarun explicitly approved the recapture. The runner was restricted to the sole stale condition
Task Home belongs to different robot resources. and used production saveTaskHome() (strict guard + monitored-state validation), regenerated and reviewed workspace evidence, reconfirmed the task, and saved the non-overwriting fdi21-r3/FDI21-current-profile-home.dentocase (SHA-256 d6da41b87c63549bdcffef06ce1df779f3ed396fe304ed826010147dfed0510c).
The first comparison call then tripped the batch's fatal identity check:
The case/task identity changed during planner execution. The saved fdi21-r3/FDI21-three-planner.dentocase (SHA-256 c67a222c47d5bd23467d48780756ad40f69a345b93e6716cb2e25ca194b4168e) contains the branch-keyed comparison with all three rows NotRun; the first
row carries that fatal text. It is not a three-planner result and must not
feed FDI31. fdi21-r3/result.json and FDI21-comparison.png were written,
but the screenshot captured the main window rather than the diagnostic dialog; it is context evidence only. Slicer exited 1 with shutdown leak warnings after functional artifacts were written; stack handoff cleaned up. The changed identity field was not recorded by this runner and remains unknown. This is a

DENTOBOT | Decision report | 2026-09-23 | Research simulation only | 54

fatal comparison-integrity stop under S6-LIVE-01, not evidence that RRTConnect failed geometrically or that RRT/RRT* executed. No FDI31 run or fresh-process reopen followed. The three-attempt ceiling is reached for this run chain;
pause for Tarun's instruction before any further runtime trial.

Follow-up source diagnosis and correction (no runtime): Tarun requested diagnosis and fixes. Read-only extraction of both saved MRML collision-audit records found exact prior/post fingerprints
778c1876…d6b6062 / 385c131a…1a3a6c741. Their 31 object records,
base, jaw/world-to-base transforms, status and runtime acknowledgement match; only generated_at_utc differs (02:59:48.929178+00:00 versus 03:01:11.456064+00:00). The current audit_fingerprint includes that
timestamp, and planApproachPhase() calls _prepare_phase_guard(), which resynchronizes/re-acknowledges the same scene. Thus the batch compared an ephemeral audit-event ID as if it were stable scene identity.

Fix: The comparison now freezes a separate content fingerprint of the acknowledged base/jaw/world-to-base/object manifest and guard policy. A changed object or policy still invalidates the batch; the exact per-trial audit ID is
retained and checked against its diagnostic session. The headless screenshot helper now captures the visible comparison dialog rather than the main window. Changed DENTOStep6State.py, DENTORobotWorkflowFacade.py, Testing/test_step6_state.py, and Testing/run_dentobot_step65_three_planner_gui.py. Focused pure tests: PYTHONPYCACHEPREFIX=/tmp/dentobot-pycache python3 -m pytest -q -p no:cacheprovider Testing/test_step6_state.py -k planner_comparison → 2 passed; changed Python compile and git diff --check passed. This is source/unit evidence only; no fourth Slicer/ROS trial was started. Next runtime plan requires explicit fresh approval under the retry ceiling.
The full Testing/test_step6_state.py run also passed (28 passed). Graphify overlay refresh was attempted and again failed with [Errno 1] Operation not permitted; no updated graph is claimed.

Operator-approved attempt 4 (FDI21 only): Started the serialized simulation-only handoff from the recaptured fdi21-r3 Home case, with canonical housing-on robot and output under fdi21-r4/. result.json, FDI21-three-planner.dentocase (SHA-256 80828de0854d640cddd107d63e7ade2537a2888a3c6d0f3746dbd27f72cecbc9), and FDI21-comparison.png were saved. The first configured planner, RRTConnectkConfigDefault, returned a Stage-3 drilling guard failure after Approach/Stage 2 succeeded; the diagnostic identifies non-approved target-tooth ↔ pneumatic-spindle collision at interpolated sample 1/1.
The RRTkConfigDefault and RRTstarkConfigDefault rows are not planner performance evidence: both failed before planning because Task Home was no longer validated in the current ROS/MoveIt session. This is not a valid three-planner comparison. No FDI31 run or offline reopen followed.

Diagnosis and source correction: planApproachPhase() checks the Task Home audit fingerprint, then _prepare_phase_guard() re-syncs the collision scene. That new, identical acknowledgement receives a new timestamp and audit ID; the next trial's Task Home exact-audit check consequently fails. In logic_robot_scene_sync.py, after a fresh scene acknowledgement the prior audit identity is now reused only if all audit fields except timestamp and fingerprint match exactly. Changed scene payload, policy, status, or acknowledgement still produces a new audit and invalidates Home. This is a source-only fix; no further runtime verdict is claimed. Commands/results:
jq extraction of the r4 comparison; PYTHONDONTWRITEBYTECODE=1 python3 -m pytest -q Testing/test_step6_state.py → 28 passed; python3 -c compile of
the changed sync module → pass. An initial py_compile was blocked by permission to write an existing __pycache__, so the non-writing compile
check was used. Next stop: operator verdict/approval before another GUI trial; only a valid FDI21 comparison may feed the sequential FDI31 and offline
reopen checks.

Operator approval and new evidence requirement: Tarun approved one corrected FDI21 runtime retry and required every diagnostic run to retain screenshot evidence and an explicit assessment of whether robot-base mount or Task Home changes could plausibly resolve a planner failure. This is a diagnostic
question, not authorization to alter placement. Added

DENTOBOT | Decision report | 2026-09-23 | Research simulation only | 55

docs/diagnostics/STEP6_GUI_AUTOMATION_SOP_2026-09-23.md, linked it from the canonical plan and verification protocol, and updated Testing/run_dentobot_step65_three_planner_gui.py to capture a base/Home context image plus selected planner-row images and numeric base/Home state. Focused source checks: PYTHONDONTWRITEBYTECODE=1 python3 -m pytest -q -p no:cacheprovider Testing/test_step6_state.py → 28 passed; non-writing compile of runner and scene-sync module → pass; git diff --check → pass.

Approved FDI21 retry / attempt 5: Started the canonical housing-on stack
with dentobot-simulation-slicer-handoff.bash, ROS domain 73, source fdi21-r3/FDI21-current-profile-home.dentocase, runner Testing/run_dentobot_step65_three_planner_gui.py, and fresh output data/dentobot-runs/step65-three-planner-fdi21-31-20260923/fdi21-r5/. Readiness passed; the case, robot and current Home/workspace gates loaded. FDI21-base-task-home.png was saved. The diagnostic process hit its 1200-s cap (exit 124); handoff reported cleanup_complete, and a read-only process check found no remaining Slicer/MoveIt processes. No completed result JSON or DentoCase and no per-row screenshot were produced. Do not infer any full task outcome or use this run as the input for FDI31/offline reopen.
Visual inspection of that image shows the robot/base context but the visible substep is 6.1 ROS Gate, not the Task Home controls: the script used substep index 1 instead of 2. The source-only correction now captures separate 6.1 base/runtime and 6.2 Task Home images; no corrected image is claimed for r5.

The retained fdi21-r5/stack.log contains planning-server messages for RRTConnectkConfigDefault → geometric::RRTConnect (25 configuration messages), RRTkConfigDefault → geometric::RRT (3), and RRTstarkConfigDefault → geometric::RRTstar (10). This is stronger algorithm configuration evidence than the earlier Slicer getter, but it does not provide complete per-trial guard outcomes. Those counts are internal planning calls, not three complete trial counts or a fair speed ranking. The long batch spans many MoveIt/Cartesian/guard calls despite a 5-s allowance per individual native plan request. The precise active call at timeout remains unknown.

Source-only runner correction after timeout: The script previously waited until the final dialog to capture every row. It now intercepts its own comparison-progress save in the GUI process, writing checkpoint.json and a selected-row screenshot immediately after each completed trial. This changes test evidence collection only, not production planning/guard logic; it has
not received a runtime check. The fdi21-r5 timeout is a new execution-cost blocker; no automatic retry or FDI31 continuation follows. Base/Home assessment: the earlier FDI21 Stage-3 target-tooth↔spindle collision may depend on whole-chain posture, so mount placement could matter; changing Home alone can affect Stage-1 route/IK seed but cannot be credited with resolving a
Stage-3 target contact without a controlled same-target test. The timeout provides no additional geometric verdict. Next bounded action requires
Tarun's review of cost/evidence and explicit approval for another runtime plan; keep base and Home fixed during any three-planner comparison.

Final source-only checks after the checkpoint and substep corrections: non-writing compile of Testing/run_dentobot_step65_three_planner_gui.py and git diff --check passed. Workspace/scripts/graphify-update.bash was attempted and failed with [Errno 1] Operation not permitted; no refreshed graph is claimed. Changed/added files in this continuation: runner, logic_robot_scene_sync.py, docs/diagnostics/STEP6_GUI_AUTOMATION_SOP_2026-09-23.md, canonical plan, verification protocol, backlog, decisions and this logbook.

Operator timing question and SOP delta: Tarun requested three fix options
for the FDI21 timeout and emphasized timestamped automation diagnostics. A read-only stack-log split shows first planner-configuration evidence at epoch 1790162597 (RRTConnect), 1790163053 (RRT), and 1790163434 (RRT*); cleanup began about 1790163647. Thus the respective configured-planner spans were approximately 456 s, 381 s, and at least 213 s, after roughly 150 s of setup. These spans include candidate search, repeated MoveIt calls, Cartesian preflight, scene/guard work and reporting; they are not native solve durations
or a performance ranking. Source confirms planApproachPhase() may examine up to 14 IK seeds and then bounded workspace-clearance detours, each potentially issuing its own native joint plan and downstream chain preflight. The 5.0-s

DENTOBOT | Decision report | 2026-09-23 | Research simulation only | 56

setting bounds an individual native planning request, not the entire trial. The automation SOP now requires flushed UTC and monotonic timestamps at setup, trial/phase boundaries, screenshot/save and timeout so a future cap leaves the active phase identifiable. This is documentation only; the runner does not yet implement that timing instrumentation.

Operator choice — A now, C after evidence; total-budget option B rejected: Tarun explicitly eliminated the proposed total per-planner trial budget and requested timestamp instrumentation, then measured optimization only after the first output. This does not rescind the separate earlier Task Home Experiment B in the canonical planner plan. Tarun also objected to treating base/Home reasoning as an afterthought. The r4 FDI21 diagnostic is specific: Home→PreEntry and PreEntry→Entry passed, while Stage 3 hit a target-tooth↔pneumatic-spindle guard collision. A different Home could change selected candidate/IK seed; a different mount could change the available whole-arm/tool-frame options. Neither directly removes a collision at the identical TCP/tool frame, and the r5 timeout adds no new geometry verdict. These are hypotheses requiring frozen-case comparison, not automatic changes.

A source implementation: Testing/run_dentobot_step65_three_planner_gui.py now appends and fsyncs timeline.jsonl events with UTC, monotonic elapsed, planner and call IDs, contexts, durations and failure boundaries. Test-only wrappers time the existing Goal-1 trial, scene/guard setup, PreEntry IK, clearance-candidate generation, joint plans, joint-segment diagnostics, Cartesian plans, chain preflight and waypoint guard. The already added per-trial checkpoint.json now contains a conservative first-failed-stage base/Home hypothesis, along with frozen placement evidence and screenshots. No production planner/guard method, candidate limit, robot pose or collision policy was changed by this A instrumentation. Testing/test_step6_state.py contains one focused pure check for UTC/monotonic timeline output and the Stage-3 hypothesis boundary. Commands: Graphify query of the facade/callback path; source and r4/r5 log inspection; focused pytest
PYTHONDONTWRITEBYTECODE=1 python3 -m pytest -q -p no:cacheprovider Testing/test_step6_state.py -k step65_runner_timeline_and_placement_hypothesis → 1 passed; non-writing compile of the runner → pass. No Slicer/ROS runtime
was started. Next: inspect the exact A diff and run git diff --check; then
seek a new bounded runtime approval. Option C is limited to the measured dominant repeated work after A evidence, with fresh guard checks retained. Final focused check includes the timing wrapper itself: the same test passed after asserting paired phase_start/phase_end events and nonnegative
duration (1 passed, 28 deselected). git diff --check and non-writing
runner compile passed. Graphify overlay refresh was attempted and again failed with [Errno 1] Operation not permitted; no graph freshness claim is made.

Operator-approved A runtime, FDI21 r6 (one bounded attempt): Tarun approved one 20-minute, simulation-only, canonical housing-on comparison from the recaptured current-profile Home case; no base/Home change, hardware, FDI31 continuation or retry was authorized. The source SHA-256 was d6da41b87c63549bdcffef06ce1df779f3ed396fe304ed826010147dfed0510c. Preflight focused pytest passed (1 passed, 28 deselected), git status confirmed the existing dirty branch, and the container process check found no
active Slicer/MoveIt stack. Command: docker exec dentobot-slicerros2 bash -lc
with ROS Jazzy/install sourced, ROS_DOMAIN_ID=73, DENTOBOT_DIAGNOSTIC_NO_SPINDLE_COLLISION=false, FDI21 source and r6 evidence paths, then dentobot-simulation-slicer-handoff.bash --stack-log ... -- timeout
1200s xvfb-run -a ros2 launch slicer_ros2_module slicer.launch.py using Testing/run_dentobot_step65_three_planner_gui.py. Stack startup explicitly
reported dentobot.urdf, diagnostic housing-off false. Exit 124 at the cap; handoff reported cleanup_complete.

Evidence directory:
data/dentobot-runs/step65-three-planner-fdi21-31-20260923/fdi21-r6/. timeline.jsonl records case open at 60.4 s, Step 5C verified at 66.5 s, PreparedBranch activated at 70.5 s, ROS connected at 107.0 s, and Task Home validated at 109.5 s. It contains phase timestamps and the complete RRTConnect checkpoint at 1050.4 s. checkpoint.json freezes branch, task, trajectory, profile, base, Home and collision-audit identities; it marks RRTConnect Fail, RRT and RRT* NotRun at checkpoint time. The RRTConnect

DENTOBOT | Decision report | 2026-09-23 | Research simulation only | 57

trial spent approximately 874 s; eight completed guard_waypoints calls accounted for 813.39 s (largest 141.8 s), while 14 joint-plan calls totaled 4.6 s and 14 Cartesian calls 21.97 s. These are nested phase durations, not independent totals to add. RRT began, but timeout interrupted its second waypoint guard; no completed RRT or RRT* result exists and no combined result.json or saved comparison DentoCase was produced.

The completed RRTConnect outcome passed Approach via workspace clearance
sample 198, then full-task Stage 3 was blocked at composed waypoint 459:
non-approved dentobot_target_tooth_2.25.156727832881888777359082987559036393993 ↔ pneumatic_spindle-Copy collision. It also reports requested combined
insertion 8.071 mm exceeding provisional 6.500 mm envelope by 1.571 mm.
This is an operator-observed/agent-extracted diagnostic outcome, not
accepted planner success or drilling authorization. FDI21-base-runtime.png, FDI21-task-home.png, and FDI21-rrtconnect-diagnostic.png are retained.
The base/Home images share a tight view and show 6.1/6.2 state rather than quantitative coordinates; exact base/Home fingerprints are in checkpoint.
The placement review remains a hypothesis: changing Home can alter candidate selection, and base placement can expose another reachable tool frame, but neither directly removes a collision at the same TCP pose. No pose was moved. Next stop: Tarun's explicit verdict on this GUI evidence; then a separately approved, bounded option-C optimization of repeated full guard work before another three-planner runtime attempt. Do not silently raise the cap or infer relative planner performance from this incomplete comparison.

Operator correction after r6: Tarun states that collision-caused planner failures need extensive, multi-angle screenshot evidence from the already written test-script pattern before asking for his advice. A table/text-only headless result deprives him of the geometric context needed for expert intervention and invites an agentic fix/approval loop. He notes this three-stage planner has been under work for over 21 days. This is his stated observation and process requirement, not an agent-inferred geometry verdict.

Source audit and bounded response: Backlog lookup routed to S6-LIVE-01; Graphify located existing diagnostic capture scripts. Read the current three-planner runner, Step 6 GUI SOP, prior FDI21 three-angle capture in Testing/run_dentobot_step65_exact_case_smoke.py, comparison callback and retained r6 checkpoint. The checkpoint has the selected candidate's first-invalid J1–J5 vector and target-tooth/spindle IDs, but r6 has no first-invalid scene image. Its diagnostic-table screenshot cannot be recast
as one. Changed the runner to reconstruct the selected first-invalid pose on the display-only goal robot, isolate the collision-audit target and goal spindle, and capture inferior, apical, and oblique views. It records exact joint state, pair, paths, or an explicit unavailable reason in the per-trial checkpoint; missing collision views cancel remaining trials for operator review. It does not change native collision geometry or authoritative robot state. Updated the SOP and canonical contract with the mandatory visual handoff; kept it under the existing task, not a parallel work item.
Focused source check:
PYTHONDONTWRITEBYTECODE=1 python3 -m pytest -q -p no:cacheprovider Testing/test_step6_state.py -k step65_runner_timeline_and_placement_hypothesis → 1 passed, 28 deselected. No Slicer/ROS/runtime was started for this source change. Next: inspect diff, run git diff --check, then stop for Tarun's
manual review; a new collision-image runtime trial is not implied by this source-only change.
Final non-writing runner compile and git diff --check passed. The required Graphify overlay refresh was attempted and failed with [Errno 1] Operation not permitted (exit 1); no refreshed graph is claimed. Changed files for
this correction: Testing/run_dentobot_step65_three_planner_gui.py, Testing/test_step6_state.py, the Step 6 GUI SOP, canonical plan, backlog and this logbook. No new runtime screenshots exist yet; r6 remains text/table-only collision evidence and cannot be offered as the requested visual verdict.

Operator-approved offline FDI21 visual recapture: Tarun explicitly approved the bounded display-only recapture proposed after r6, not another planner run. Added Testing/run_dentobot_step65_collision_recapture.py to open the SHA-256 verified fdi21-r3/FDI21-current-profile-home.dentocase, read r6's retained RRTConnect selected candidate 6/first-invalid J1–J5 state, compare the saved

DENTOBOT | Decision report | 2026-09-23 | Research simulation only | 58

base fingerprint, rebuild local URDF robot meshes via createOrUpdateRobotPlacement and updateRobotJointPoses, prepare the selected target surface using the
existing collision-scene jaw transform, and render inferior/apical/oblique
views with no ROS connection, planner call, base/Home edit or scene publication. Non-writing compile and git diff --check passed before execution. The exact command used docker exec dentobot-slicerros2, sourced ROS environment for the installed Slicer launcher only, and invoked timeout 180s xvfb-run -a ros2
launch slicer_ros2_module slicer.launch.py with this Python script and a new output directory each time. No move_group/guard stack was launched.

Attempt 1 (fdi21-r6-collision-recapture/) failed before images because this Slicer build lacks qMRMLThreeDView.resetCameraClippingRange; failure.json records the exact exception. Attempt 2 (...-r2/) used the renderer clipping
method and saved a manifest plus three PNGs, but image inspection showed only the tooth, not the spindle. Attempt 3 (...-r3/) framed both saved-model
bounds and saved three PNGs plus manifest.json. The manifest records case SHA d6da41b87c63549bdcffef06ce1df779f3ed396fe304ed826010147dfed0510c,
checkpoint SHA 49115ceaf8d3cfcf8e72444a81d6ca74e694d41587dfe97e9805be3fdc7883b1, base fingerprint 230ce2cda5723fbc41fadfd9c1f0f887710b29a444cbf73bee4daddaa394e47c, the exact five joint values and the native tooth↔spindle pair. The target model
world-RAS bounds are [-99.511,-91.399,-65.894,-54.356,18.623,41.046] mm;
spindle visual-model bounds are [-106.345,-85.794,-40.817,22.878,38.431,75.941]
mm. Their Y bounds have a 13.54-mm axis-aligned gap in this reconstruction. Visual inspection likewise shows a separated spindle and tooth in all three angles, contradicting the native guard's reported collision at waypoint 459.
The visual mesh and collision mesh share the same canonical URDF mesh/origin, but this does not establish that our offline scene reconstructs the native planning scene correctly. Treat the mismatch as unresolved state/transform/ attribution evidence, not proof of native clearance or authorization to change collision policy. The launcher returned exit 0 while logging Slicer child exit
1 after the manifest was written; this shutdown discrepancy is also retained. No Slicer/MoveIt processes remained afterward. Three scoped capture attempts have reached the retry ceiling; no fourth run or planner retry. Next bounded step is Tarun's review of the three r3 images and the mismatch packet, then a source-only native-vs-display transform attribution audit if he directs it.

Operator rejection of recapture evidence: Tarun explicitly rejected the
three r3 screenshots as invalid collision evidence: they show an aerotor spindle and a tooth-like object but do not show the colliding object in contact, so they do not support expert geometry advice. This supersedes the preceding proposed request for his visual verdict. The images remain archived only as evidence of a native/display reconstruction mismatch. No further runtime or planner trial was started. Source audit traced the retained first_invalid_joint_positions_si to the waypoint rejected by validate_task_phase_waypoints; it is a waypoint-level vector while the
native message reports collision at an interpolated sample. The target model was recreated from saved segmentation plus jaw preparation, and the spindle from local URDF FK rather than the live native planning scene. The exact cause of their 13.54-mm Y separation remains unresolved; do not claim it is solely interpolation, transformation, or a false native report. A minimal source-only fail-closed bounds-overlap check now prevents both the offline recapture and future comparison runner from calling separated model images collision views. Next: attribute the native scene object transform and exact rejected sample against the displayed models source-first, then capture only if equivalent state/geometry can be shown. Do not ask Tarun to diagnose from the invalid r3 screenshots or seek routine approval for another blind trial.

DENTOBOT | Decision report | 2026-09-23 | Research simulation only | 59

# Appendix B. Final interpretation and report provenance

Bottom line: there is a real recorded native guard rejection, a separately identified diagnostic-image defect, an incomplete comparison, and a measured performance bottleneck. Fixing one must not be presented as fixing all four.

Path A makes sense if it is run as finite evidence gates. The immediate implementation is diagnostic scene/state attribution, followed by one bounded exact-state check if approved. Base/Home reasoning is integral to the next causal decision, but only after the geometry being reviewed is the geometry actually evaluated. A manual tune-until-pass strategy is not the recommended foundation.

Report production used read-only Graphify navigation, controlled-document/source inspection, retained JSON/log and image files, Python ReportLab layout and PDF rendering. It did not start Slicer, ROS, MoveIt, load a saved case into runtime, move a robot, alter anatomy, run a planner, change guard policy or accept a milestone. Existing source edits and input cases were preserved.

Prepared 23 September 2026. The latest operator request is for time and evidence to make an informed decision. No further runtime action is implied by delivery of this report.

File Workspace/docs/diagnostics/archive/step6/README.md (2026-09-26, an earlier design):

# Archived Step 6 working records

These are preserved historical analyses and proposals, **not** the current work order. The active [renovation plan](../../STEP6_RENOVATION_IMPLEMENTATION_PLAN_2026-09-25.md), [later-reference index](../../STEP6_LATER_WORK_AND_ADJACENT_IDEAS_2026-09-25.md), [FDI31 P0 milestone contract](../../FDI31_GUI_PLANNER_P0_PLAN_2026-09-21.md), [backlog](../../../backlog.md), and [TASKS.md](../../../TASKS.md) determine current scope and acceptance. Dated PDFs, screenshots, JSON evidence and logbooks remain at their original locations.

| Original path under `docs/diagnostics/` | Archived file | Historical status and existing owner of open work |
|---|---|---|
| `STEP6_PLANNER_MANUAL_DIAGNOSIS_CONTEXT_2026-09-20.md` | [Manual diagnosis](STEP6_PLANNER_MANUAL_DIAGNOSIS_CONTEXT_2026-09-20.md) | Its §21 restart order and “current” P1 conclusion describe the September 19 FDI31 session and are superseded. FDI11/FDI21 and planner follow-ups remain `S6-LIVE-01` in the backlog. |
| `PLANNER_IMPLEMENTATION_MAP_2026-09-20.md` | [Implementation map](PLANNER_IMPLEMENTATION_MAP_2026-09-20.md) | Dated code map and diagnostic history. Current Step 6 source and task state require fresh inspection; `S6-LIVE-01/05`, `S6-REUSABLE-CASE-SETUP` and Step 5 owners retain open gates. |
| `FDI31_PLANNER_RECOVERY_CAMPAIGN_1.md` | [Campaign 1 plan](FDI31_PLANNER_RECOVERY_CAMPAIGN_1.md) | Bounded historical r4 experiment contract and hashes. `S6-REUSABLE-CASE-SETUP` and `S6-LIVE-01/03` retain case/route review; no P6/P7 authorization follows. |
| `FDI31_PLANNER_RECOVERY_REPORT.md` | [Campaign 1 report](FDI31_PLANNER_RECOVERY_REPORT.md) | Later §§AU–AW supersede the front-matter P4-not-run statement: P3 phase-static accepted 21 candidates, P4 retained six sampled insertion witnesses, and P5 was a sampled approach pass. None is a full GUI route, physical fit or clinical acceptance. P1 input/scene review and P5 operator verification remain open under the existing Step 6 owners; adjacent Step 4/5 evidence retains its own owners. |
The base-pose feasibility plan was restored to [active diagnostics](../../DENTOBOT_Base_Pose_Feasibility_Explorer_Diagnostic_Plan_2026-09-25.md) on 25 September. Its shared diagnostic metrics are current Step 6 work; automated sweeps and robot-design comparisons remain later work.

Historical literal paths, manifests and hashes inside these records are retained as provenance, not active links. The [GUI automation SOP](../../STEP6_GUI_AUTOMATION_SOP_2026-09-23.md) stays in place because it still governs future diagnostic runtime.

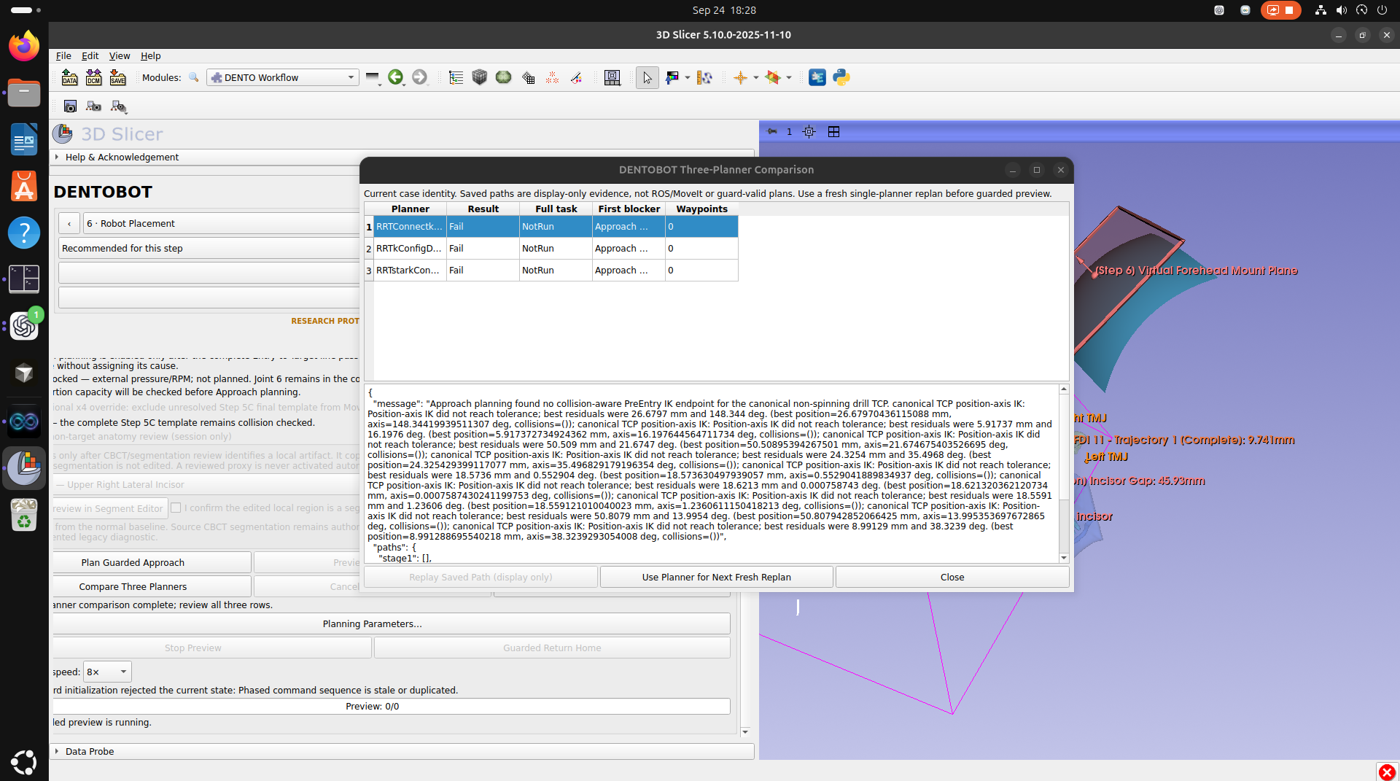
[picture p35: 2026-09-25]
Workspace/docs/diagnostics/evidence/fdi11-step6-2026-09-24/01-comparison-earlier.png

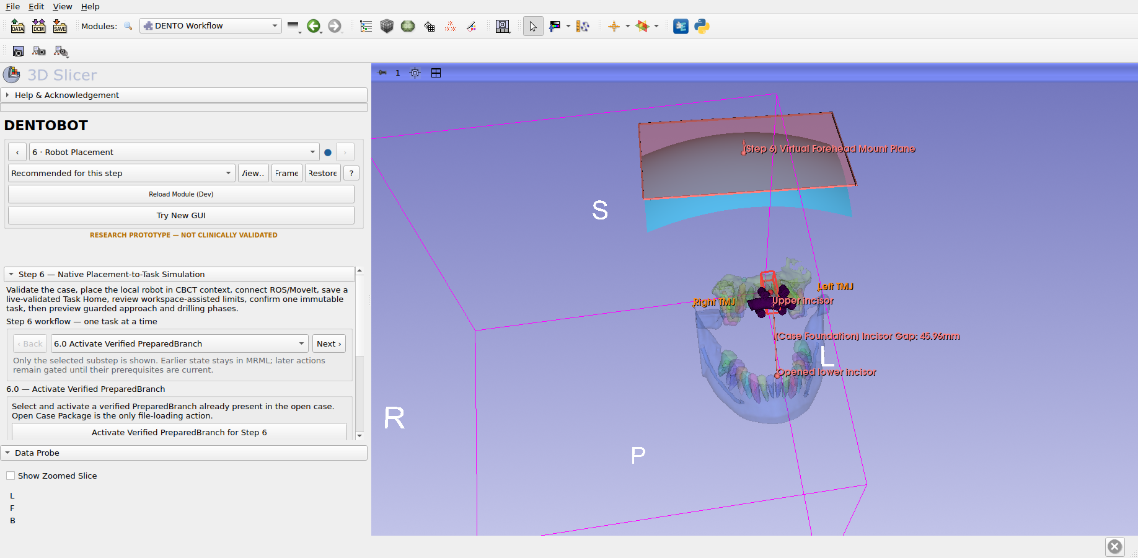
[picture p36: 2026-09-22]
Workspace/docs/diagnostics/evidence/2026-09-22-multitarget-step5c/headless-r1/step6a-fdi21-preparedbranch-active-ui.png

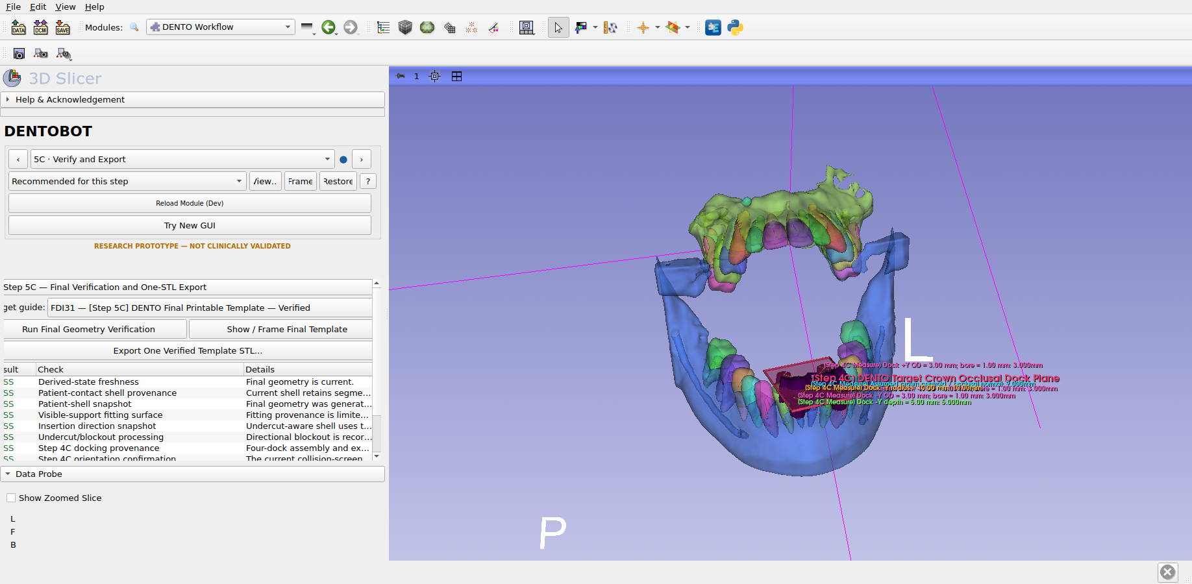
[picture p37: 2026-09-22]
Workspace/docs/diagnostics/evidence/2026-09-22-multitarget-step5c/headless-r1/step5c-third-alternate-fdi31-ui.png

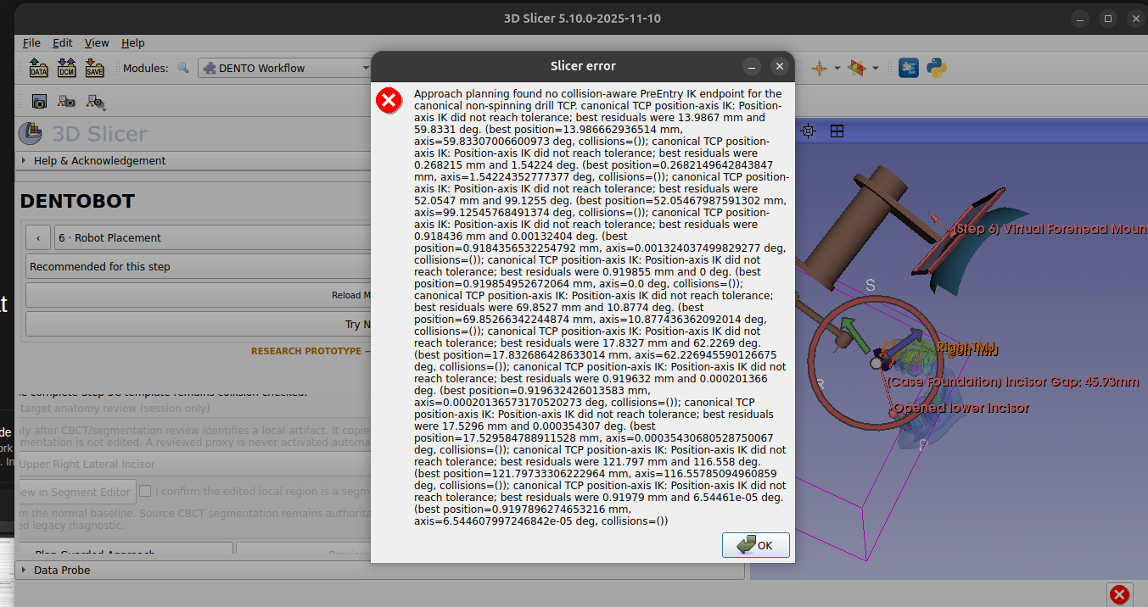
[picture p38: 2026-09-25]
Workspace/docs/diagnostics/evidence/fdi11-step6-2026-09-24/04-later-ik-error.png

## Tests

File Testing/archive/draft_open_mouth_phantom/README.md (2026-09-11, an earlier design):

# Archived draft open-mouth phantom

This directory preserves the retired, generic BodyParts3D phantom logic and
its focused SlicerROS2 smoke script for historical explanation only.

The archive is not imported by `DENTOWorkflow`, is not a supported product
path, and is intentionally absent from `Testing/verification_matrix.json`.
Existing MRML scenes may still contain these nodes; production loading hides
them, and they never satisfy Case Foundation or Step 6 eligibility.

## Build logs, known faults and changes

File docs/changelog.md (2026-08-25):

# DENTOBOT Low-Level Changelog

## Purpose

This file is the append-oriented, textual version history for DENTOBOT. It
records material source, documentation, configuration, dependency, model, and
accepted-specification changes in enough detail for an AI coding agent or a
researcher to reconstruct how the repository evolved.

Every entry must contain an explicit date, time, and timezone. One timestamp
may cover a cohesive change batch when separate timestamps would be redundant.
Retrospective entries must state when they were recorded and whether the
original event time is unknown. Do not include patient identifiers, secrets,
or credentials.

Use newest-first ordering. Each entry should state:

- what changed and why;
- files or subsystems affected;
- behavior added, removed, preserved, or superseded;
- verification performed and its environment;
- limitations, pending validation, and whether anything was reverted.

## 2026-08-25 03:55:00 IST (UTC+05:30) — Connected case-package save repair

- Made programmatic package snapshots explicitly exclude SlicerROS2 nodes and
  suspend the live ROS-active base flag, restoring runtime state only in the
  current scene after save. The package audit remains fail-closed.
- Added a connected-save round trip that verifies the live flag resumes,
  package reload contains no ROS state, and geometry is unchanged at `1e-6`.
  The focused run printed `DENTOBOT_CONNECTED_CASE_SAVE_PASS`; AST/static
  checks and all 97 host tests passed.
- The separate historical package fixture is currently missing; that
  compatibility check was not claimed. Reload and operator save retry remain.

## 2026-08-25 03:18:00 IST (UTC+05:30) — Step 5B voxel-island cleanup

- Reproduced the representative `test1_5b2.mrb` fusion failure as one
  85,852-voxel printable region plus regions of 3, 1, and 1 voxels.
- Verified all four independent shell-contact branches were present; generalized
  numerical-island cleanup from one voxel to a resolution-aware maximum
  0.1 mm³ per extra region only when one printable region remains. Larger
  disconnected geometry still fails closed, and raw/removed metrics persist.
- The repaired case generated one watertight occupied volume with four branch
  records. Focused and full synthetic Slicer regressions, AST parsing, and 97
  host tests passed. Physical fit, strength, manufacturing, and clinical
  acceptance remain open.

## 2026-08-25 00:52:52 IST (UTC+05:30) — Ubuntu workflow launcher repair

- Made the final Ubuntu `docker exec` request `-it` only from an interactive
  terminal, allowing Cursor and other non-TTY callers to launch the attached
  Slicer GUI without Docker rejecting stdin.
- Closing the successful session exposed orphaned ROS/MoveIt children after
  Slicer's known VTK-leak exit. The simulation launch now owns a separate
  process group and cleanup performs bounded INT, TERM, then KILL escalation.
- Added focused regression coverage and documented that the host Docker
  service must be active. The incident's first failure was the absent daemon
  socket; starting `docker.service` restored the existing runtime.
- Bash syntax, five focused tests, the bounded process-group probe, the
  97-test host suite, full launcher preflight, backend health, ROS-package
  build, live Slicer/DENTOWorkflow startup, and the simulation `ready:true`
  contract passed. No hardware execution or robot motion ran.

## 2026-08-24 20:53:23 IST (UTC+05:30) — Ubuntu native Step 6 simulation workflow

- Rebuilt Step 6 as one gated DENTOWorkflow sequence with persistent
  base/proxy/Task-Home/limits/task intent and transient ROS/MoveIt runtime.
- Added explicit geometry-preserving CBCT context, shared Views/expert return,
  provisional drill-tip frame, native façade Goal/IK/Plan, split target
  collision objects, and task-fingerprinted approach/drilling phase guarding.
- Recorded 95 host-test passes plus focused Slicer restore/persistence and
  isolated ROS phase-guard PASS markers. Supplied old cases remain truthfully
  stale/review-gated. No hardware motion, drilling, or clinical validation.
- Synchronized the changed active/canonical Markdown documents to their existing
  Drive IDs only; provider metadata retained parents and matching byte sizes.

## 2026-08-17 16:06:00 IST (UTC+05:30) — Robot-workspace publication checkpoint

- Created local commits `28d940f` and `901ee17` for the manual Step 6 placement
  and disposable open-mouth trial. The environment rejected the non-force push
  to `https://github.com/ghostarun/DentoBot.git` pending explicit approval for
  that named private-source destination; the branch remains ahead locally.
- Replaced 11 established Markdown files in their existing Drive IDs using
  committed-`HEAD` snapshots and uploaded exactly one new August 17 dated log,
  ID `1t9OpsCvyiTBCELkSZ-0X9XulF7iieB8i`. Untracked phantom meshes, QA images,
  unrelated dirty workstation edits, secrets, and patient data were excluded.
- The closing process audit found four retained headless Slicer test trees.
  SIGTERM was sent only to their exact `SlicerApp-real` PIDs; the follow-up
  query returned no Slicer/Xvfb/open-mouth QA process.
- At 16:18 IST the developer explicitly approved the named GitHub destination.
  The non-force push advanced `codex/ubuntu-migration` to `f25bf6f`; remote
  verification returned the matching full SHA.

## 2026-08-17 15:52:00 IST (UTC+05:30) — Draft open-mouth robot workspace

- Extended DENTOWorkflow Step 6 with a disposable BodyParts3D
  neurocranium/maxilla/mandible loader, four approximate TMJ/incisor landmarks,
  deterministic pure-hinge jaw opening to an approximately 40 mm final incisor
  gap, reset/delete actions, visible gap measurement, and active-stage display
  restoration.
- Preserved the existing robot mount-plane drag/snap, local button/keyboard
  base tuning, and six manual joint controls. No ROS state, controller, hardware
  command, or patient data entered the workflow.
- Four host geometry tests, Python/UI/static checks, focused Slicer logic and
  widget tests, MRB save/reopen, and a visually inspected graphical Xvfb run
  passed. The graphical marker reported a 40.001 mm gap, seven robot models,
  and three phantom models. The QA exposed and fixed hidden Step 6 display
  nodes before the passing rerun. The repository close-day gate passed 34
  Python AST files, two UI files, and eight Markdown fence checks; backend
  tests were explicitly skipped because inference code was unchanged and no
  backend interpreter was supplied.
- This is synthetic disposable design evidence only. The 40 mm value is not a
  literal mandibular translation, and clinical jaw mechanics, physical-session
  controls, forehead registration, TCP, reach/collision, and hardware motion
  remain unverified.

## 2026-08-17 15:48:35 IST (UTC+05:30) — Private CRD host-stability policy

- Preserved the required private CRD/Xfce virtual desktop and accepted its
  same-user force-stop handoff before physical login.
- Configured the physical GDM/GNOME path for Xorg after journal accounting
  showed its Wayland greeter consumed nearly one full CPU for three days.
- Installed and applied swappiness 10 plus 128 MiB background/512 MiB hard
  dirty-page thresholds for the rotational system disk. Kept the verified
  systemd-oomd and Docker safeguards unchanged.
- Extended the health report and controlled workstation documentation. Bash
  syntax, whitespace, exact sysctl values, GDM configuration, OOM status, and
  the live health report passed. Reboot activation and an overnight CRD soak
  remain pending; no active Slicer process was interrupted and no Git/Drive
  publication occurred.

## 2026-08-14 19:18:17 IST (UTC+05:30) — Draft zero/base alignment/J4 direction

- Made the photographed manual state q=0, aligned link-1's mounting face with
  RViz XY using the integration root, and negated J4's prismatic axis while
  keeping its 0–75 mm positive range.
- Seven direct and eight Jazzy-reported tests passed. The isolated six-joint TF
  probe, zero-state publication, expected burr coordinates, RViz/AABB visual
  check, and exact cleanup passed.
- The developer's open prior session was not interrupted and needs restart to
  reload the URDF. This is draft coordinate evidence only; no physical home,
  Slicer, IK, hardware, Git publication, or Drive sync occurred.

## 2026-08-14 18:46:30 IST (UTC+05:30) — Draft 5 mm AABB workspace feedback

- Added collision-mesh-derived link AABBs, a 5 mm non-adjacent-pair warning,
  green/red RViz markers, and live CAD burr-origin coordinates to the manual
  articulation tool. Warnings remain advisory.
- Six direct tests passed; Jazzy reported seven tests with no failure. RViz
  consumed the marker topic, the neutral warning panel/boxes were visually
  inspected, and clean shutdown left no process. Neutral has two conservative
  box overlaps.
- Corrected one symlink-install path-validation error before the passing run.
  This is not exact/swept/head/patient collision or safety evidence. No Slicer,
  IK, hardware motion, Git publication, or Drive sync occurred.

## 2026-08-14 18:19:23 IST (UTC+05:30) — Manual robot-joint articulation

- Added package-owned PyQt controls and neutral/manual/external joint-state
  modes, plus a host launcher for the six controls and RViz. Display units are
  degrees/millimetres; ROS messages remain radians/metres.
- Extended static tests and added an independent six-joint runtime TF probe.
  Jazzy build/test, every joint probe, neutral/articulated RViz loading, and
  clean shutdown passed.
- This is synthetic forward-kinematics evidence only. Physical calibration,
  collision, IK, Slicer, controllers, hardware, motion, Git publication, and
  Drive sync remain out of scope.

## 2026-08-14 17:07:00 IST (UTC+05:30) — Documentation and publication checkpoint

- Reconciled the Daily Compass with the controlled Ubuntu documentation. No
  filled working-memory entries were present, so no unverified requirement or
  clinical claim was promoted.
- Updated the workbook reconciliation date and current phase, then rendered
  and visually inspected all ten pages without finding a layout defect.
- The developer authorized a non-force Git publication and in-place Google
  Drive documentation sync. The two established Drive mirrors remain separate;
  no patient, runtime, model, or robot-operation data is in scope.

## 2026-08-14 16:50:57 IST (UTC+05:30) — ROS description integration checkpoint

- Added the simulation-only `dentobot_description` ROS 2 package, received
  mesh copies with enforced checksums, package-resolvable URDF, neutral
  joint-state publisher, optional RViz configuration, package tests, and
  provenance/limitations documentation.
- Added a KDL-compatible massless `base_link` above the unchanged supplied
  inertial/movable tree and a bootstrap-managed source-space link so colcon can
  discover the nested package beside the generic CMake Slicer extension.
- Jazzy build/test passed. The final headless launch published all six neutral
  joints, resolved `base_link -> burr`, and shut down cleanly with no remaining
  node/process. RViz, calibration, collision, controller, hardware, and motion
  evidence remain pending. No Git/Drive publication occurred.

## 2026-08-14 15:18:25 IST (UTC+05:30) — Ubuntu remote-workstation containment

### Added and changed

- Added Docker init reaping, a 512-task ceiling, reduced relative CPU weight,
  OOM preference for the host desktop, and a 30-second stop grace period to
  the reusable SlicerROS2 service.
- Made the launcher refuse a duplicate live Slicer session and verify the
  applied runtime controls.
- Bounded synthetic Slicer phases with exact Xvfb ownership and cleanup, an
  internal process-group timeout, and an outer Docker-client guard.
- Added a read-only workstation health report and updated controlled runtime,
  architecture, decision, reproducibility, task, and dated-logbook records.

### Verification and limits

- Bash syntax, Compose rendering, whitespace checks, launcher/backend health,
  and the complete synthetic Bridge B round trip passed. The recreated
  container used docker-init as PID 1 and had zero zombies or remaining
  Slicer/Xvfb processes after the test.
- A deliberate one-second timeout exited 124 and also left no Slicer/Xvfb
  descendant. The verified-idle container was then stopped; the launcher will
  start it on demand.
- ShellCheck was unavailable. Overnight observation remains pending. The GDM
  Wayland greeter's sustained one-core use remains a host follow-up requiring
  local sudo authentication; it was not reconfigured. No patient data,
  inference segmentation, GUI performance acceptance, robot action, Git
  publication, or Drive sync occurred.

## 2026-08-11 20:09:17 IST (UTC+05:30) — Shared Windows/Linux runtime contract

### Added and changed

- Added the Slicer-independent `DENTOPlatform.py` adapter contract for direct
  Linux and Windows-to-WSL execution, explicit launcher configuration,
  Windows-drive artifact mapping, and shell-free backend commands.
- Added a machine-local Windows configuration template and PowerShell launcher
  for native Windows Slicer plus the existing WSL2 inference environment.
- Extended DENTOWorkflow launcher configuration to both platforms, including
  execution mode, WSL distribution where applicable, absolute Linux Python,
  Slicer-visible artifact root, and explicit CPU/CUDA device. Updated the
  backend UI to report the active adapter and device.
- Made the Ubuntu launcher and Compose boundary explicitly `local`/`cpu` and
  retained its pinned Linux SlicerROS2 Docker deployment.
- Documented that Docker is not required for Windows Steps 0–5. Current
  upstream SlicerROS2 1.2 is Ubuntu/Jazzy oriented, so ROS-integrated operation
  remains assigned to the verified Linux profile; Windows Docker GUI hosting
  is not claimed.

### Verification and limits

- Five ordinary-Python platform tests, 13 inference tests, Python compilation,
  Qt UI XML parsing, Bash/static checks, real-host Linux launcher preflight,
  and focused Slicer bridge/module-initialization checks passed. Optional
  OpenVINO enumeration now runs in a bounded child so a native driver crash is
  reported instead of killing backend health. PowerShell parsing and
  end-to-end Windows acceptance remain pending because PowerShell is
  unavailable on the Ubuntu workstation.
- No Git publication, Drive sync, Slicer GUI launch, patient data operation,
  inference run, ROS motion, or robot action occurred in this change batch.

## 2026-08-10 15:59:55 IST (UTC+05:30) — Zoomable Step 5C and constrained cut height

### Fixed

- Preserve mouse-wheel zoom in the isolated ROI-aligned view under both
  orientation lock modes. Explicit isolation still establishes the initial
  ROI fit; subsequent edit actions retain the user's zoom.
- Constrain the simple Markups plane to one origin point on the Step 5B ROI Z
  axis with normal ROI `+Z`. Hide transform handles, persist its ROI reference,
  reapply the constraint after reload, and validate it before cutting.
- Added focused ROI-plane coverage. Python/UI/whitespace/repository static
  checks passed; live Slicer behavior remains pending. No Git publication or
  Drive sync occurred.

## 2026-08-10 15:38:25 IST (UTC+05:30) — Stable in-view trajectory correction

### Fixed

- Prevented Entry/Target edits from rebuilding the selected slider angle on a
  new world-reference basis and jumping to another circumferential MPR view.
- Hold the native slice matrix during a Markups drag. At release, minimally
  transport the previous plane normal onto the corrected axis and continue
  slider changes by angle delta; an in-plane edit retains the exact plane.
  Reset remains the deterministic world-reference-zero operation.
- Added focused transport/fallback geometry cases. Python, UI XML, and
  whitespace checks passed; live correction UX and Slicer-native execution
  remain pending. No Slicer launch, Git publication, or Drive sync occurred.

## 2026-08-10 14:50:42 IST (UTC+05:30) — Trajectory-oriented oblique MPR verification

### Added

- Added Step 4A longitudinal oblique MPR over the authoritative Entry/Target
  Markups line and referenced source CBCT. A singularity-safe orthonormal frame
  drives native `SliceToRAS`; the trajectory is slice Y, a slider-rotated
  transverse vector is slice X, and their cross-product is the plane normal.
- Added enable, `-180°..+180°` rotation, zero reset, live state, automatic
  valid-point updates, same-line 2D projection, coalesced rendering updates,
  and restoration of prior slice/composite/display state across disable/save/
  exit/close/cleanup and Step 5C isolation.
- Added focused Slicer-native frame/matrix regression coverage. Python/UI/
  whitespace checks passed; no Slicer process was launched, so runtime tests,
  overlay/rotation UX, persistence, and FPS remain pending. No new volume,
  trajectory, inference, robot action, Git push, or Drive sync occurred.

## 2026-08-10 14:11:28 IST (UTC+05:30) — Corrected Step 5C isolation and ROI ownership

### Changed

- Replaced the fixed-anterior multi-view Step 5C camera with a temporary
  ROI-aligned one-up 3D yaw workspace. Zero yaw looks along ROI `+Y`, with ROI
  `+X` right and `+Z` up; the ROI Z size controls top-to-bottom parallel fit.
- Added separate persisted non-yaw and yaw locks, coalesced conditional camera
  correction, complete layout/camera/crosshair/visibility restoration, and a
  strict separation between isolation and plane/curve placement.
- Superseded user-adjustable Step 5B bounds. Step 4A and Step 5B workflow ROIs
  are now locked, non-selectable from views, and have no interactive handles;
  Step 5B recomputes automatic bounds before geometry generation while keeping
  the legacy role string for MRB compatibility.

### Verification and limits

- Python compilation, Qt UI XML parsing, whitespace checks, and the repository
  static gate passed. Added Slicer-native camera-math, ROI policy, and relock
  assertions, but did not execute them because no Slicer launch was authorized.
- Native mouse yaw, visual viewport fit, presentation restoration, and
  performance remain live acceptance items. No inference, patient data, ROS,
  robot, motion, drilling, fabrication, Git push, or Drive sync occurred.

## 2026-08-07 17:50:52 IST (UTC+05:30) — Step 4A–5C workflow hardening and shell finalization

### Changed

- Completed the Step 4A multi-trajectory backlog with persisted target
  identity, per-tooth target bounds, deterministic lineage colors, sequenced
  labels, target restoration, non-retargeting selection, and a strict
  two-point Entry/Target invariant. Extended the same lineage presentation
  through Steps 5A, 5B, and 5C.
- Isolated Step 5B's role-owned shell ROI from Step 4A bounds, repaired legacy
  cross-role state without duplication, added workflow visibility controls,
  role-gated delete/reset behavior, raw shell/sleeve generation, provenance,
  topology metrics, stale state, and MRB persistence.
- Added Step 5C as a non-destructive Dynamic Modeler finalization and export
  boundary. It supports capped Plane Cut positive/negative selection and an
  adjustable surface-snapped closed-curve inside/outside trim with explicit
  capping/topology validation. STL export now rejects the Step 5B raw shell
  and requires a Current, source-matched, watertight finalized shell plus the
  Current sleeve.
- Added clean owned-subtree deletion, Step 5B-to-5C cascade cleanup, an
  isolated anterior world-RAS interaction view, expert Dynamic Modeler
  handoff, and persisted edit/source/Dynamic-Modeler provenance.

### Verification and limits

- Python compilation, Qt UI XML, and whitespace checks passed. Focused Plane
  Cut, Curve Cut, Step 5B/5C lifecycle, UI, view, legacy-scene, and lineage
  regressions passed. The registered complete Slicer-native suite reached
  `DENTOWORKFLOW_FULL_SUITE_PASSED`; its source-build process reported known
  VTK debug leaks only after the pass marker.
- The interaction view is world-RAS, not a dental/occlusal frame. No automatic
  coverage percentage, gingival-margin detection, fit/print validation,
  clinical approval, or drilling authorization was added. Representative
  anatomy and dentist acceptance remain pending.
- No patient data, inference, ROS, robot, motion, drilling, or fabrication
  operation ran.

## 2026-08-06 19:21:52 IST (UTC+05:30) — Portable launcher configuration and tracked Ubuntu workspace

### Changed

- Added a Git-tracked `Workspace/` layer containing the formerly loose Ubuntu
  Compose definition, launcher/helper scripts, active workspace notes, and
  top-level agent entrypoint. Preserved their established workspace paths as
  relative symlinks and added a safe, non-overwriting bootstrap plus Git
  helper.
- Added a tracked `.dentobot.env` template and one untracked populated local
  file. The launcher now derives repository/workspace and Conda-environment
  roots, exports the complete runtime contract, and invokes the canonical
  Compose file with explicit workspace bind sources.
- Added automatic Ubuntu launcher configuration to DENTO Workflow. Launcher
  paths are displayed but not persisted into MRB state; manual interpreter
  and run-record fields are retained as advanced overrides. Added an explicit
  explanation of local per-operation NIfTI/JSON run records.
- Updated Ubuntu Bridge A/C harnesses and the synthetic Bridge B launcher to
  consume the same runtime environment variables instead of workstation
  interpreter paths.
- Expanded `.gitignore` for local machine configuration, test/coverage
  outputs, and patch residue. Disabled pytest's cache provider in the close
  check so root-owned container cache residue cannot produce host warnings.
- Installed the already pinned pytest 8.4.2 dependency into the external
  Conda backend. Slicer's embedded Python was not modified.

### Verification and limits

- Shell syntax, compatibility symlinks/bootstrap, canonical and compatibility
  launcher lookup, Git helper, and rendered Compose configuration passed.
- Python AST and Qt UI XML checks passed. `pip check` and all 13 inference
  tests passed in the dedicated Python 3.12 backend.
- No Slicer GUI/native test, inference/model run, medical image, patient data,
  robot, motion, drilling, or fabrication action was performed. Interactive
  launcher-value display and backend health remain the next Slicer check.
- GitHub CLI authentication was found invalid before publication; local
  commit and Drive synchronization are handled separately from that external
  authentication gate.

## 2026-08-04 13:42:57 IST (UTC+05:30) — Safe draft-output deletion and Ubuntu rendering guide

### Changed

- Added dedicated confirmed delete buttons for the selected Step 4A
  DENTOBOT trajectory and Step 5A DENTOBOT draft support-anatomy model.
- Added role-gated deletion logic that clears the relevant workflow reference
  and removes captured display/storage auxiliaries only when no remaining
  scene node references them. Target, reviewed segmentation, bounds, ordered
  supports, shared auxiliaries, and unrelated user nodes remain intact.
- Added Slicer-native lifecycle coverage for rejecting unrelated nodes,
  selective destruction, MRB save/reload without dangling references, retained
  source state, and successful recreation.
- Added a repository `README.md` describing general Ubuntu container graphics
  requirements, with the verified Intel integrated-graphics path prioritized.
- Updated controlled architecture, roadmap, transfer, agent-state, changelog,
  and logbook records. The developer's new workflow batches notes and requests
  approval before Drive/Git synchronization rather than syncing every prompt.

### Verification and limits

- The host/container path reported direct `Mesa Intel(R) Graphics (ARL)`,
  OpenGL 4.6, `i915` render-node use, and Slicer nice level 0. Workload-level
  perceived FPS remains for the developer to confirm.
- `git diff --check` and `Infrastructure/close_day_checks.sh` passed 20 Python
  ASTs, two Qt UI files, eight controlled Markdown files, and Markdown fences.
  Backend tests were skipped because backend source was unchanged.
- The added Slicer-native deletion/persistence test was not run. No inference,
  segmentation, model download, patient data, robot, motion, drilling,
  fabrication, or clinical operation occurred.

## 2026-08-03 21:33:16 IST (UTC+05:30) — Step 5A arbitrary-count support anatomy

### Changed

- Added persistent Step 5A parameters for ordered manual support-tooth IDs and
  the draft model reference.
- Added a Step 5A panel that reuses the Step 4A target and lets the user check
  any positive number of other whole-tooth segments. No adjacency, arch, side,
  ordering, or maximum-count rule is inferred.
- Added validation and one-model generation by appending unmodified target and
  support closed surfaces, with source transform preservation and namespaced
  selection/review/geometry provenance.
- Added explicit Current/Stale behavior: selection or segmentation-content
  changes retain and recolor the prior model, and regeneration requires an
  explicit Update.
- Added Slicer-native logic coverage for ten supports, a two-support update,
  invalid selections, geometry counts, provenance, persistence, transform
  preservation, review gating, and stale state.
- Updated controlled architecture, roadmap, traceability, agent state,
  changelog, and logbook. Pre-existing interpreter-path and process-lifecycle
  worktree changes were preserved and are not attributed to this increment.

### Verification and limits

- `python3 -m py_compile DENTOWorkflow/DENTOWorkflow.py` passed.
- `Infrastructure/close_day_checks.sh` passed Git whitespace, 20 Python ASTs,
  two Qt UI XML files, and eight Markdown fence checks. Backend tests were
  skipped because backend source was unchanged.
- The Slicer-native test was added but not run. The developer remains the live
  Slicer acceptance authority; create/update and scene save/reopen remain
  pending observation.
- No Slicer, inference, model download, patient data, robot process, motion,
  drilling, fabrication, or clinical operation occurred.
- Step 5A produces draft source anatomy only. It does not generate a shell,
  contact surface, sleeve, drill channel, printable template, or approved
  dental guide.

## 2026-08-03 17:36:17 IST (UTC+05:30) — Deterministic Slicer process shutdown

### Changed

- Made the Slicer 5.10 fallback `QProcess` a child of the workflow widget and
  added explicit signal disconnection, close, and deferred deletion after
  final output is drained.
- Made the Bridge A health harness release its workflow widget before Slicer
  shutdown and added a direct headless-Slicer launcher whose exit code is the
  test authority.
- Preserved the pre-existing uncommitted Ubuntu default-interpreter change;
  this lifecycle batch did not author or revert it.

### Verification and limits

- Static close checks passed for 20 Python ASTs, two Qt UI files, eight
  controlled Markdown files, Markdown fences, and Git whitespace.
- The full checkpoint backend returned successful explicit-CPU health with
  PyTorch 2.10.0+cpu, TotalSegmentator 2.16.0, and OpenVINO 2026.2.0 seeing
  `CPU`.
- Two consecutive network-disabled, source-read-only, disposable Slicer 5.10
  probes passed in 7.758992707 and 5.913129843 seconds. Both Slicer processes
  and backend children exited; both disposable containers were removed.
- Initial diagnostic attempts correctly exposed that the ordinary Compose
  container has only the minimal Bridge B Conda runtime and that `ros2 launch`
  does not propagate a failed Slicer child status. A first disposable attempt
  also exposed an `xvfb-run` wrapper leak; the final probes used explicit Xvfb
  ownership and cleanup.
- No segmentation, model download, patient data, robot process, motion, or
  clinical operation occurred. Clean image reconstruction is the next gate.

## 2026-07-31 15:43:26 IST (UTC+05:30) — Ubuntu checkpoint published

- Authenticated GitHub HTTPS through the official browser/device flow as
  `ghostarun` using a temporary unpacked Ubuntu GitHub CLI. No Git credential
  or token was added to the repository.
- Published `codex/ubuntu-migration` and annotated tag
  `checkpoint/2026-07-31-1511-IST` without force. Verified both remote refs;
  the branch and peeled tag target equal
  `1a3d40c1a390283e4884eb0815f0a2b0659ade13`.
- This supersedes the close entry's push blocker. The checkpoint tag remains
  fixed at the tested source/documentation state; this entry is a later
  documentation-only publication record.
- GitHub CLI reported that this workstation lacks an encrypted credential
  keyring and stores its token in the user's filesystem-protected CLI config.
  The token value is not recorded here or in Drive.

## 2026-07-31 15:07:38 IST (UTC+05:30) — Slicer-launched Ubuntu run and checkpoint close

### Completed

- Added a Slicer 5.10-compatible asynchronous `QProcess` fallback because its
  installed `launchConsoleProcess` helper lacks the newer callback and
  non-blocking arguments. The fallback reconstructs Slicer's startup
  environment, decodes PythonQt output incrementally, preserves bounded live
  logging, and retains completion/cancellation callbacks.
- Added headless Bridge A and Bridge C Ubuntu integration harnesses. Bridge A
  passed with explicit CPU health and OpenVINO reporting `CPU`.
- Added software-only SlicerROS2 image-bridge and geometry-sensitive synthetic
  MRML/NIfTI round-trip harnesses for later bounded regression. Their presence
  is not a claim that those separate harnesses passed during this close.
- The final Slicer-launched Bridge C run returned `status: ok`, produced 54
  validated segments, and saved a 25.7 MB MRB. Added artifact hashes and the
  ordered post-checkpoint task gates to controlled documentation.

### Known defect and close disposition

- The headless Slicer process did not exit cleanly after its controlling
  session was interrupted, even though the backend completed and no inference
  child remained. Stale exact test processes were identified and terminated.
  Deterministic process shutdown is the first next task and must use
  health-only probes before another expensive inference is considered.
- A local 11.0 GB Docker checkpoint image was created for immediate recovery;
  clean Dockerfile reconstruction remains pending.
- Static close checks and backend/Slicer evidence are recorded separately.
  No runtime image, model, medical image, MRB, or result artifact was added to
  Git or Drive. No robot/hardware motion or clinical validation occurred.
- Close verification passed `git diff --check`, 19 Python AST parses, two UI
  XML parses, eight-document fence checks, container `pip check`, and all 13
  backend tests. No further Slicer/inference execution was used for closeout.
- The local checkpoint commit/tag were created. GitHub push was attempted
  without force but stopped before upload because this Ubuntu clone lacks
  readable HTTPS credentials. Remote publication remains an explicit
  authentication blocker, not a successful push.

## 2026-07-31 14:45:38 IST (UTC+05:30) — Native Ubuntu CPU workflow baseline

### Added and changed

- Added a platform-neutral local Linux process adapter alongside the existing
  Windows/WSL adapter. Ubuntu defaults use the isolated
  `/opt/dentobot-venv/bin/python`, persistent native run paths, and explicit
  CPU execution.
- Generalized backend health and segmentation contracts to an explicit
  `cpu`/`cuda:0` device without fallback. Health records OpenVINO availability
  and visible devices; segmentation metadata records the requested/actual
  device.
- Added TotalSegmentator 2.16 CPU compatibility handling, explicit transitive
  task-298 model metadata/cache guarding, and CPU-safe Slicer metrics/provenance.
- Added Ubuntu CPU constraints, a complete top-level requirement set, an
  idempotent backend installer, a SlicerROS2 Dockerfile, and a Compose
  device-mapping example for the Intel accelerator.
- Added backend CLI/health/segmentation tests and a headless Slicer import,
  closed-surface, review-metadata, and MRB-save test using a public fixture.
- Added a root `AGENTS.md`, close-day check script, and standing
  `"close my day"` / `"close the day"` procedure covering traceability,
  commit/tag/push, in-place Drive synchronization, verification, and next-day
  notes.
- Updated architecture, project context, roadmap, reproducibility, and Ubuntu
  transfer documentation with the native execution boundary and verified
  evidence.

### Verification and limits

- `pip check` passed; all 13 backend tests passed in Python 3.12.3 with one
  multiprocessing/fork deprecation warning; the complete Slicer-native
  `DENTOWorkflowTest` passed in Slicer 5.10.
- TotalSegmentator CPU inference on Slicer's public 360 x 360 x 330 dental
  CBCT completed in 217.85 seconds. Geometry and label validation passed with
  54 detected labels. Slicer imported 54 segments, created closed surfaces,
  attached review metadata, and saved a 25.7 MB MRB.
- Model tasks 113, 115, and 298 were downloaded explicitly to the persistent
  local cache and cryptographically inventoried. Models and runtime artifacts
  remain outside Git and Drive.
- OpenVINO is installed, but the existing container sees only CPU because host
  accelerator devices are not mapped. Intel NPU dental inference is not
  claimed: TotalSegmentator has no direct OpenVINO device and conversion plus
  numerical validation remain pending.
- Clean-image reconstruction, independent MRB reopen, full UI-driven
  asynchronous Bridge A/B/C, cancellation/error robustness, and anatomical or
  clinical validation remain pending. No robot or hardware motion occurred.

## 2026-07-31 11:33:22 IST (UTC+05:30) — Git handoff published for Ubuntu transfer

### Transfer state

- Pushed `codex/target-tooth-trajectory` to GitHub, publishing the Step 4A
  implementation, correction batch, manual acceptance record, and Ubuntu
  transfer guide.
- Updated the active transfer checklist from push-pending to published. The
  exact final remote commit is intentionally reported in the session handoff
  because a commit cannot contain its own hash.
- Synchronized the changed transfer, changelog, and logbook files to their
  existing Drive IDs and verified the mirror after replacement.

### Verification and limitations

- Verified the remote-tracking feature branch after the final push; the local
  working tree is clean and no commits remain only on Windows.
- No merge to `main` was performed. Ubuntu retrieval must use
  `codex/target-tooth-trajectory` and compare `rev-parse HEAD` with the exact
  handoff hash.
- No Slicer, WSL, CUDA, inference, model, DICOM, robot, or hardware process was
  launched.

## 2026-07-31 03:45:04 IST (UTC+05:30) — Step 4A manual acceptance and transfer closeout

### Accepted and documented

- The developer manually retested the Step 4A correction batch on the retained
  teeth phantom in Slicer 5.12.2 and reported that it works as intended.
- Accepted the current PoC interaction scope: target-priority highlighting,
  target bounding ROI and point constraint, paired Entry/Target placement,
  and the undo/reset/lock controls.
- Superseded the active acceptance wording that relied on an isolated
  automated Slicer run. Those earlier results remain historical diagnostic
  evidence, while developer-run live testing is the acceptance authority.
- Recorded the current testing policy: rigorous ordinary-Python logic and
  static verification remain required, but assistant-launched Slicer testing
  requires new explicit authorization for the specific action.

### Transfer preparation

- Updated the Ubuntu transfer guide with a checked Windows closeout,
  Git-versus-non-Git handoff boundary, minimum manifest for approved non-Git
  material, exact-hash verification, first Ubuntu session order, and expanded
  Step 4A compatibility checks.
- Confirmed that Git tracks the extension, inference package, dependency
  manifests, controlled documentation, and transfer guide. Installed Slicer,
  environments, model weights, generated caches, run artifacts, research
  data, credentials, and the existing Ubuntu Compose/ROS workspace remain
  outside Git.
- Preserved the non-destructive migration rule: clone into a comparison
  location and do not overwrite `/home/light-tarun/dentobot`.

### Verification and limitations

- All 11 repository Python files passed AST parsing. The DENTO Workflow UI
  parsed successfully with 156 uniquely named UI objects; all 71 Python UI
  references and all 29 connected callbacks resolved. All eight local
  Markdown files had balanced code fences, and `git diff --check` passed with
  line-ending warnings only.
- Observer and transient-state cleanup paths were reviewed: parameter-node,
  segmentation, display-node, and trajectory observers are removed on
  rebinding/exit/cleanup, and cached valid trajectory points are cleared or
  removed during planning resets and node changes. This is static lifecycle
  evidence, not a runtime leak measurement.
- The ordinary Windows Python could not run `Inference/tests` because
  `pytest` is not installed. No dependency was installed, WSL was not used,
  and the separately controlled backend test status was not reclassified.
- Replaced the changed controlled Markdown files in the existing
  `IITM Dentobot/docs` Drive mirror without changing their IDs, added
  `UBUNTU_TRANSFER.md` as the eighth mirrored file with ID
  `1lQ9QJFInl-FM-OuqOBJBIcNmLCjrc0_X`, and verified all eight names, IDs, and
  byte sizes against the local canonical files.
- This closeout changes documentation only; no Slicer, WSL, CUDA, inference,
  model, DICOM, robot, or hardware process was launched.
- The manual report does not establish anatomical accuracy, clinical safety,
  procedure semantics, MRB persistence on Ubuntu, or Slicer 5.10
  compatibility.
- The feature branch still requires a final push and exact remote-hash
  confirmation before Ubuntu retrieval is complete.

## 2026-07-30 23:09:46 IST (UTC+05:30) — Step 4A manual-test correction batch

### Developer findings recorded

- Target assignment and Step 3 review highlighting behaved independently;
  the planning target did not own the 2D/3D viewport emphasis.
- Entry and Target could be placed anywhere in the CT world instead of being
  constrained to the selected tooth.
- The dentist prefers precise placement in 2D slices; the requested
  horizontal orientation/focus lock needs a defined anatomical reference
  plane.
- Mouse placement created `F_*` fiducial lists instead of populating one
  two-point trajectory.
- The workflow exposed no direct undo, reset, or point-lock controls.

### Corrected

- Made the Step 4A target the priority 2D/3D segmentation highlight and
  synchronized the Step 3 tree back to that target.
- Added a locked orange `vtkMRMLMarkupsROINode` for the active tooth's
  axis-aligned world-RAS bounds.
- Added continuous bounds enforcement: reject a new out-of-bounds point or
  restore a moved point to its last valid location.
- Added explicit Markups point-defined, point-modified, and point-removed
  observers after the expanded test found that the generic MRML modified event
  could arrive before the first point became defined.
- Reproduced the `F_*` failure in Slicer 5.12.2. `StartPlaceMode(0)` retained
  the line node ID but reset the active class to
  `vtkMRMLMarkupsFiducialNode`. Reasserting the active line class and node
  after entering place mode fixed the state.
- Changed the placement instruction to one Entry-then-Target action and kept
  the Markups line's maximum at two points.
- Added Undo Last Point, confirmed Clear Both Points, and lock/unlock controls
  for a complete non-zero in-bounds pair.
- Persisted the active target-bounds ROI and associated it with the selected
  segmentation, segment, and trajectory.

### Verification and limitations

- The complete Slicer-native suite passed in Slicer 5.12.2 revision
  `f7879b5`.
- A widget-level correction test passed target-priority highlight in 2D/3D,
  ROI creation, out-of-bounds Entry and Target rejection, restoration of an
  existing point moved outside the bounds, corrected line placement class,
  undo, confirmed reset, and lock/unlock.
- Orientation lock was not guessed. It is recorded as Step 4B until scanner
  axial versus occlusal versus tooth-local reference is decided with the
  dentist.
- The AABB is a coarse phantom-PoC constraint, not an anatomical or clinical
  safety boundary. Manual phantom retest remains pending. WSL, inference,
  CUDA, models, DICOM, robot, and hardware were not launched.

## 2026-07-30 22:14:45 IST (UTC+05:30) — Step 4A automated Slicer acceptance

### Authorized verification

- After explicit developer authorization, launched isolated hidden Slicer
  5.12.2 processes without starting WSL, inference, CUDA, models, DICOM,
  robot, or hardware operations.
- Ran the complete `DENTOWorkflowTest` Slicer-native suite.
- Exercised the actual widget path with an already-existing synthetic
  segmentation containing one whole tooth, one pulp segment, and one jaw
  segment.
- Confirmed that selecting the segmentation enables Step 4A and produces one
  eligible FDI 16 target plus the placeholder.
- Selected and persisted `tooth-16`, created a
  `vtkMRMLMarkupsLineNode`, labelled its points Entry and Target, retained
  `SlicerRASmm` and `Draft` attributes, and verified the known 3-4-12
  trajectory length of 13.0 millimetres.
- Saved and reopened a synthetic MRB and confirmed restoration of the target
  segment ID, segmentation reference, trajectory reference, trajectory
  geometry, and trajectory-to-segmentation node reference.

### Test-harness findings and limitations

- The first widget-harness attempt constructed the widget without a parent,
  causing Slicer's base class to call `setup()` before subclass initialization.
  The harness was corrected to use Slicer's registered-widget construction
  pattern; no product source change was required.
- The first persistence fixture used empty segments and could not be stored as
  an MRB. Adding synthetic closed-surface representations corrected the
  fixture, after which save/reopen passed.
- The Windows app-control bridge was unavailable, so the test used Slicer's
  supported command-line/Python runtime rather than clicking the developer's
  visible Slicer instance.
- Manual point placement on the retained teeth phantom and Ubuntu Slicer 5.10
  compatibility remain pending. The disposable test script, result JSON, and
  synthetic MRB were removed after verification. Nothing in product source
  was reverted.

## 2026-07-30 20:39:31 IST (UTC+05:30) — Step 4A segmentation-selection refresh fix

### Observed and corrected

- During the first interactive Step 4A test, the developer reported that the
  target-tooth selector remained disabled after an existing segmentation was
  selected in the Step 3 review panel.
- Confirmed that Step 4A does not require a new inference run or any additional
  backend output. It consumes existing whole-tooth segment names ending in
  valid two-digit FDI codes.
- Added an explicit planning refresh after the review-segmentation selection
  handler. This avoids relying on parameter-node observer ordering that may
  differ across Slicer versions.
- Restored the agreed `Step 4A` identifier in the panel and controlled
  documentation.

### Verification and limitations

- Static Python parsing and UI XML/reference checks passed after the fix.
- Interactive retest in the developer's running Slicer session remains
  pending. No inference, WSL, CUDA, model, DICOM, or hardware process was
  launched for this correction.
- Selecting a tooth in the Step 3 explorer remains a non-destructive review
  highlight. The target must be explicitly chosen in Step 4A.

## 2026-07-30 18:25:34 IST (UTC+05:30) — Step 4A target-tooth and draft trajectory inputs

### Added and changed

- Added the Step 4A planning panel to DENTO Workflow.
- Added persistent `targetToothSegmentId` and
  `vtkMRMLMarkupsLineNode` parameter-node state.
- Restricted target choices to whole-tooth records from the authoritative
  segmentation. Pulp, canal, jaw, implant, restoration, and other anatomy
  remain reviewable but are excluded from target-tooth selection.
- Added draft trajectory creation and selection, explicit Entry/Target point
  labels, interactive Markups placement, world-RAS coordinates, and Euclidean
  length.
- Associated each configured trajectory with its target segmentation using an
  MRML node reference and with its target segment using namespaced
  `DENTOBOT.*` attributes.
- Cleared stale target associations when the selected segmentation changes, the
  target is cleared, or the retained segment no longer qualifies.
- Added Slicer-native logic-test source for target filtering, invalid targets,
  target references, point labels, partial and complete lines, a known
  13-millimetre trajectory, coincident points, and parameter-node
  persistence.
- Updated the controlled architecture, roadmap, and agent state.
- Added `docs/UBUNTU_TRANSFER.md` with the verified Git boundary, non-Git
  manifest, safe comparison clone procedure, Slicer 5.10 compatibility gates,
  and external-backend migration sequence.

### Preserved

- The authoritative segmentation, Step 3 review/correction behavior, inference
  process contract, source CBCT, masks, and run artifacts are unchanged.
- The increment does not define procedure-specific anatomy, approve a plan,
  calculate clearance, generate a patient-specific template, perform
  registration, or authorize drilling.
- The disabled legacy trajectory scaffold remains unchanged as historical
  source; its two-point creation and length concepts were reimplemented under
  current DENTO Workflow ownership rather than enabling the old module.

### Verification and limitations

- All 11 repository Python files passed static AST parsing without importing a
  Slicer module in ordinary Python.
- `DENTOWorkflow.ui` parsed as XML; all 67 Python `self.ui.*` references
  resolve, all statically discovered callbacks resolve, and UI object names
  are unique.
- `git diff --check` passed apart from informational line-ending warnings.
- An ordinary Windows-Python `pytest` attempt did not run because that
  interpreter does not have pytest installed. This is not a failure of the
  Slicer-native planning tests or the separately controlled WSL environment.
- Slicer, WSL, CUDA, TotalSegmentator, DICOM, research data, robot, and
  hardware processes were not launched. Module reload, interactive placement,
  the Slicer-native test, and MRB persistence remain pending in Slicer 5.12.2;
  compatibility must then be verified in Ubuntu Slicer 5.10.
- Nothing was reverted.

## 2026-07-24 16:11:03 IST (UTC+05:30) — Step 3C acceptance and quiet negative test

### Accepted and changed

- Recorded the developer's successful completion of the complete Step 3C
  checklist in Slicer 5.12.2. The selected label, authoritative segmentation,
  and source CBCT were correctly handed to Segment Editor; correction state,
  baseline-metric messaging, correction activity, and MRB persistence behaved
  as intended.
- Marked Steps 3A, 3B, and 3C developer-verified at the current Step 3 scope.
- Reworked the missing-source negative test to temporarily remove and restore
  the source reference on the existing valid test segmentation instead of
  creating a scene-owned orphan segmentation. This preserves the same
  `ValueError` coverage while avoiding expected Subject Hierarchy warnings.

### Verification and limitations

- The application workflow and Step 3C checklist were run by the developer in
  Slicer 5.12.2 and reported successful.
- The observed `CorrectionWithoutSource` Qt messages were traced to the
  deliberate negative-test fixture, not the real segmentation or correction
  workflow. The revised quiet fixture is statically validated here but still
  needs one future in-Slicer self-test run to confirm the console is quiet.
- Replaced `AGENTS.md`, `DEVELOPMENT_PLAN.md`, `changelog.md`, and
  `logbook.md` in place in the Drive mirror. Metadata readback confirmed the
  existing file IDs and byte sizes matching the local files.
- No anatomical or clinical accuracy claim was added. Corrected-mask metric
  recomputation and per-label review states remain optional later work.
- Nothing was reverted.

## 2026-07-24 15:50:44 IST (UTC+05:30) — Step 3C correction handoff

### Added and changed

- Added `Edit Selected Label in Segment Editor` to the segmentation review
  panel.
- Added strict handoff validation for the selected segment and the
  segmentation's persisted `DENTOBOT.SourceVolume` CBCT reference.
- Configured Slicer's built-in Segment Editor with the authoritative
  segmentation, source volume, and selected segment instead of copying masks
  or embedding another editing implementation.
- Starting a correction revision now conservatively sets the whole
  segmentation to `Needs Correction`, records a UTC correction-start time,
  and marks imported voxel/volume metrics as pre-correction inference
  baselines.
- Added content-specific observation of source-representation modifications
  and segment addition/removal while DENTO Workflow is active. These changes
  record the mask-edit timestamp and invalidate a previously `Reviewed`
  result; display, naming, selection, and metadata changes do not.
- Updated selected-label and provenance UI language so original inference
  metrics are not presented as current measurements after correction begins.
- Extended Slicer-native logic tests for source-volume validation, correction
  handoff state, metric validity, edit timestamps, automatic review
  invalidation, and invalid segment IDs.
- Recorded the developer's confirmation that Steps 3A and 3B work as intended
  in Slicer 5.12.2 and that the universal review state is intentional.

### Preserved

- The authoritative segmentation node, source geometry, original inference
  artifacts/provenance, and universal review-state model are preserved.
- No per-label approval state, corrected-mask metric recomputation,
  registration, planning, navigation, robotics, ROS, or clinical validation
  was added.

### Verification and limitations

- Official Slicer source and Slicer 5.12 developer documentation were checked
  for Segment Editor setters and `vtkSegmentation` event semantics.
- All 11 repository Python files passed AST parsing without importing the
  Slicer module in system Python. The Qt UI passed XML parsing; all 57
  `self.ui.*` references and 16 statically discovered callbacks resolve, UI
  object names are unique, Markdown fences are balanced, and `git diff
  --check` is clean.
- Slicer, WSL, CUDA, TotalSegmentator, DICOM, patient data, and installed
  Slicer files were not launched or modified during implementation.
- Replaced `AGENTS.md`, `ARCHITECTURE.md`, `DEVELOPMENT_PLAN.md`,
  `changelog.md`, and `logbook.md` in place in the Drive mirror. Folder
  readback confirmed stable file IDs and byte sizes matching the local files.
- Step 3C's Slicer-native test and manual Segment Editor handoff remain
  pending in the developer's Slicer 5.12.2 runtime. Nothing was reverted.

## 2026-07-24 15:06:56 IST (UTC+05:30) — Step 3B metrics, provenance, and review state

### Added and changed

- Extended the `Segmentation Review` panel with selected-label details:
  human-facing anatomy, source label, FDI number, model label ID, voxel count,
  and physical volume in mm³ and cm³.
- Added a compact provenance summary for run ID, source CBCT, backend and
  TotalSegmentator versions, model task/dataset/crop, CUDA device, inference
  and total time, and completion timestamp.
- Added segmentation-level `Unreviewed`, `Needs Correction`, and `Reviewed`
  workflow states with a persistent UTC update timestamp. UI warnings state
  explicitly that `Reviewed` is not clinical validation.
- Added a proper `DENTOBOT.SourceVolume` MRML node reference and versioned
  `DENTOBOT.SegmentMetricsJson` data keyed by stable segment ID. New Bridge C
  imports now persist the validated result's per-label metrics and expanded
  provenance directly on the segmentation node.
- Added a non-fatal compatibility path for older imported Bridge C results:
  when versioned review metadata is absent, the module attempts to validate
  and migrate the retained `result.json`. Missing or invalid retained
  metadata produces a visible warning without discarding the segmentation.
- Consolidated Bridge C provenance assignment through the new metadata
  enrichment routine after successful output validation and import.
- Extended Slicer-native logic tests for source-node references, per-label
  metric mapping, provenance rendering, review-state persistence, and invalid
  review-state rejection.
- Updated the controlled agent, architecture, and development-plan documents
  to record the Step 3B schema and remaining Step 3C boundary.

### Preserved

- Segment masks, reference geometry, inference commands, CUDA-only policy,
  artifact validation, and the Step 3A display behavior are unchanged.
- Segment Editor correction, edit-driven review invalidation, clinical
  approval, registration, planning, navigation, robot control, and ROS remain
  outside this increment.

### Verification and limitations

- All 11 repository Python files passed AST parsing without importing the
  Slicer module in system Python.
- `DENTOWorkflow.ui` passed XML parsing; all 54 `self.ui.*` references resolve
  to declared UI objects, and all 15 statically discovered signal callback
  methods exist.
- Slicer, WSL, CUDA, TotalSegmentator, DICOM, patient data, and installed
  Slicer files were not launched or modified.
- Updated the existing Drive files for `AGENTS.md`, `ARCHITECTURE.md`,
  `DEVELOPMENT_PLAN.md`, `changelog.md`, and `logbook.md` in place. Folder
  readback confirmed the same five file IDs and matching byte sizes.
- The extended Slicer-native test, known-label metric comparison, and MRB
  scene save/reopen acceptance remain pending in official Slicer 5.12.2.
  Nothing was reverted.

## 2026-07-24 15:00:25 IST (UTC+05:30) — Git version-control baseline

### Added and changed

- Added a repository-root `.gitignore` covering Python caches and packaging
  output, local environments, CMake build products, editor metadata, runtime
  artifacts, local environment files, and common medical/research image
  formats.
- Established Git as the source-version history from this project state
  forward. Material implementation and architecture commits continue to be
  described in this changelog and in `docs/logbook.md`.

### Safety and limitations

- Source medical/research data remains outside version control by default.
- No patient data, credentials, installed Slicer files, dependencies, models,
  or application behavior were changed.
- The GitHub remote is pending the repository URL and the initial push is
  therefore not part of this local baseline.

### Verification

- The ignore rules and staged baseline were inspected with Git locally.
- No Slicer, WSL, CUDA, model, robot, or hardware process was run.

## 2026-07-24 14:29:14 IST (UTC+05:30) — Step 3A segmentation explorer

### Added and changed

- Added a `Segmentation Review` panel to `DENTOWorkflow.ui` with a persistent
  segmentation selector, anatomy/FDI search, grouped label tree, visibility
  checkboxes, show/hide/isolate actions, 2D/3D visibility toggles, and opacity
  sliders.
- Added deterministic review descriptors for TotalSegmentator labels,
  including human-facing FDI tooth names and categories for teeth, pulp,
  jaws, neural/mandibular canals, sinuses/airway, restorations/implants, and
  other anatomy.
- Added reusable MRML logic for segment enumeration, visibility, isolation,
  selected-segment emphasis, and global 2D/3D display control.
- Reused the existing `teethSegmentation` parameter-node reference. Existing
  Bridge C results are auto-selected by their `DENTOBOT.BridgeOperation`
  provenance when no persistent selection exists.
- Added segmentation/display observers with cleanup and rebinding across
  node replacement, module exit, scene close, and cleanup.
- A successful Bridge C completion now collapses the backend panel and opens
  the review panel.
- Added Slicer-native logic coverage for FDI/category mapping, result
  discovery, visibility, isolation, emphasis, opacity, and invalid inputs.

### Preserved

- Bridge C command construction, inference, NIfTI validation, segmentation
  import, provenance, and source geometry were not changed.
- Review actions modify only MRML display properties; they do not duplicate,
  edit, resample, or otherwise change segmentation masks.
- Step 3B review state/provenance and Step 3C Segment Editor handoff remain
  outside this increment.

### Verification and limitations

- The Python source passed AST parsing. The Qt Designer file passed XML
  parsing; all 38 `self.ui.*` references resolve to declared UI objects, and
  the new selector has an MRML-scene connection.
- The display methods were checked against official Slicer segmentation
  display-node documentation.
- Slicer was not launched. The new Slicer-native test and manual 60-label UI
  acceptance run remain pending in official Slicer 5.12.2.
- No WSL, CUDA, model, inference, DICOM, patient data, installed Slicer file,
  or run artifact was changed. Nothing was reverted.

## 2026-07-24 13:55:18 IST (UTC+05:30) — Formal inference reproducibility baseline

### Added and changed

- Added `docs/REPRODUCIBILITY_AND_TRACEABILITY.md` as the controlled,
  professional installation, reconstruction, evidence, and diagnostic
  procedure for the external inference environment.
- Reworked `Inference/README.md` into a concise operational entry point with
  the Slicer/WSL boundary, validated setup commands, explicit model-cache
  preparation, verification, bridge configuration, commands, artifact rules,
  and limitations.
- Reduced `Inference/environment.yml` to a Python 3.10.20 Conda bootstrap and
  added exact validated top-level pip manifests under
  `Inference/requirements/`.
- Added `Inference/validated-environment.json`, recording backend 0.2.0,
  Slicer 5.12.2, the successful package/CUDA/GPU/model-task baseline, and the
  scope of the evidence run without patient identifiers.
- Updated the architecture, project context, development plan, and agent rules
  to distinguish controlled professional documentation from raw audit records.

### Deferred by decision

- Bridge C's verified happy path is accepted for continued development.
  Failure injection, cancellation/process cleanup, five segmentation-focused
  WSL tests, MRB persistence, anatomical validation, a complete transitive
  lock, and a clean-machine rebuild remain explicit later TODOs.
- The top-level pins are not described as a complete dependency lock.

### Verification and limitations

- The JSON baseline was parsed, dependency files and internal documentation
  links were checked, and Markdown structure was reviewed locally.
- Version values were grounded in the retained successful Bridge C
  `result.json` and official TotalSegmentator, PyTorch, Conda, and NVIDIA WSL
  installation guidance.
- No Slicer, WSL, model, CUDA, or inference process was launched in this
  documentation/dependency-manifest change. No patient data, installed Slicer
  file, model cache, or run artifact was modified or uploaded.
- Nothing was reverted.

## 2026-07-23 21:41:08 IST (UTC+05:30) — Bridge C real-CBCT runtime evidence

### Verified

- Developer-supplied evidence from official 3D Slicer 5.12.2 confirms that the
  Bridge C happy path completed without a displayed error.
- The selected real CBCT had dimensions 580 x 580 x 300, 0.25 mm isotropic
  spacing, signed-short scalar storage, valid IJK-to-RAS geometry, and was the
  same `Unnamed Series` shown as **Bridge input**.
- The GPU-only TotalSegmentator path completed teeth task 113 with
  craniofacial crop task 115 and returned an integer multilabel NIfTI matching
  the source 580 x 580 x 300 grid.
- Slicer retained `DENTOsegmentation_Teeth_93cbd5d1` with 60 validated
  segments. Colored masks were visible in the 2D slice views and the
  closed-surface representation was visible in the 3D view.
- The displayed metrics were 75.2 seconds total runtime, 48.65 cm^3 foreground
  volume, and 2.16 GiB peak GPU allocation. The terminal report showed
  `status: ok` and retained the research-output warning.

### Status changes

- Updated `AGENTS.md` and `DEVELOPMENT_PLAN.md` from “Bridge C runtime pending”
  to “core happy-path runtime verified.”
- This evidence verifies model-cache readiness, GPU inference, output contract
  validation, MRML import, label naming/coloring, and immediate 2D/3D display
  for one representative CBCT.

### Limitations

- The screenshot demonstrates technical execution and visual alignment, not
  anatomical accuracy, clinical validity, completeness against ground truth,
  or suitability for planning.
- The five new WSL unit tests, explicit error/cancellation paths, exact
  dependency lock, and MRB save/reopen persistence are not evidenced by this
  update and remain pending.
- No source code, installed Slicer file, environment, model, or patient data
  was changed or uploaded. Nothing was reverted.

### Files affected

- `docs/AGENTS.md`
- `docs/DEVELOPMENT_PLAN.md`
- `docs/changelog.md`
- `docs/logbook.md`
- Corresponding raw Markdown mirrors in `IITM Dentobot/docs`

## 2026-07-23 21:34:29 IST (UTC+05:30) — Documentation mirror and final Bridge C static checks

### Added

- Established `IITM Dentobot/docs` in the connected Google Drive as a raw
  Markdown mirror of the repository's six documentation files.
- Added a standing agent rule: local repository documents remain canonical;
  changelog/logbook requests include an in-place sync of their corresponding
  Drive files plus any other design documents changed in the same batch.
- Explicitly excluded patient data, DICOM/NIfTI, segmentations, run artifacts,
  models, credentials, and other non-document data from this Drive workflow.

### Verified since the preceding entry

- `dentobot_inference --help` and `segment-teeth --help` both parsed and exposed
  the expected Bridge C command and required arguments.
- All 23 `self.ui.*` references in `DENTOWorkflow.py` matched objects in the Qt
  Designer file.
- Ten Python files passed AST parsing; the UI passed XML parsing;
  `pyproject.toml` passed TOML parsing at version `0.2.0`; all Markdown code
  fences were balanced.
- A stale-contract search found no active documentation still claiming that
  TotalSegmentator/Bridge C was a future or unimplemented command.

### Drive synchronization

- Grounded the existing Drive folder `IITM Dentobot` with ID
  `1e7AWrEeVLctMKfWaBGiqv0Ck8p0AbFWh`.
- Created its `docs` child folder with ID
  `1M5uicX_Vkk2Y130p5k4rme1TjfavWJuO`.
- Uploaded all six `.md` files as raw Markdown and verified the child-folder
  inventory. Future updates must replace those file contents in place and
  preserve their Drive IDs.

### Files affected

- `docs/AGENTS.md`
- `docs/PROJECT_CONTEXT.md`
- `docs/ARCHITECTURE.md`
- `docs/changelog.md`
- `docs/logbook.md`
- Connected Google Drive folder `IITM Dentobot/docs`

### Limitations

- This update adds documentation mirroring, not automatic background
  synchronization. Sync occurs when explicitly requested through an agent
  session with the connected Drive available.
- Bridge C WSL tests, model inference, Slicer import/display, and scene
  round-trip verification remain pending from the previous entry.
- No implementation, installed Slicer file, environment, model, or patient
  artifact was changed or reverted.

## 2026-07-23 21:14:55 IST (UTC+05:30) — Bridge C GPU teeth segmentation source

### Added

- Bumped `dentobot-inference` from `0.1.0` to `0.2.0` and added the
  `segment-teeth` command.
- Added GPU-only TotalSegmentator `teeth` inference on CUDA device 0 with no
  CPU fallback.
- Added a cache-only runtime guard for both required open models:
  ToothFairy3 task 113 and craniofacial crop task 115. The guard requires
  dataset metadata, plans, and final checkpoint files and prevents
  TotalSegmentator's Python API from downloading weights during a Slicer run.
- Added schema-versioned success/failure JSON with model/package versions,
  input/output geometry, CUDA identity, inference/total runtime, peak allocated
  and reserved GPU memory, detected labels, per-label voxel counts and physical
  volumes, and actionable error codes.
- Added backend validation for three-dimensional geometry, affine/spacing,
  integer/nonnegative labels, known teeth label IDs, and nonempty foreground.
  Incomplete output NIfTI is removed after a failed run while `result.json` is
  retained.
- Added five backend tests covering metrics, unknown labels, missing input,
  complete offline model caches, and missing model caches.
- Added a **Run Teeth Segmentation (GPU)** workflow action. It exports the
  exact visible selected volume, reuses the asynchronous WSL adapter, validates
  the returned report, geometry, label IDs, and voxel counts, and only then
  imports the result.
- Added deterministic label names/colors, a persistent
  `vtkMRMLSegmentationNode` parameter reference, binary-labelmap and
  closed-surface representations, 2D/3D visibility, compact inference metrics,
  and `DENTOBOT.*` provenance attributes.

### Changed

- Renamed the reproducible Conda environment definition to `dentobot` and
  aligned it with the working Python 3.10 environment.
- Added the optional `segmentation` dependency extra for
  `TotalSegmentator>=2.11,<3`.
- Updated backend setup/runtime instructions and the governing architecture,
  roadmap, and agent state to describe Bridge C accurately.
- Recorded the developer's confirmation that the selector-authority fix made
  the real-CBCT Bridge B round trip work.

### Files affected

- `Inference/src/dentobot_inference/segmentation.py`
- `Inference/src/dentobot_inference/cli.py`
- `Inference/src/dentobot_inference/__init__.py`
- `Inference/tests/test_segmentation.py`
- `Inference/pyproject.toml`
- `Inference/environment.yml`
- `Inference/README.md`
- `DENTOWorkflow/DENTOWorkflow.py`
- `DENTOWorkflow/Resources/UI/DENTOWorkflow.ui`
- `docs/AGENTS.md`
- `docs/PROJECT_CONTEXT.md`
- `docs/ARCHITECTURE.md`
- `docs/DEVELOPMENT_PLAN.md`
- `docs/changelog.md`
- `docs/logbook.md`

### Verification and limitations

- Static AST parsing passed for all ten relevant Python source/test files.
- The Qt Designer UI file parsed successfully as XML, and `pyproject.toml`
  parsed with version `0.2.0` and both optional extras.
- Backend tests could not be run from Windows base Python because that
  interpreter has neither `pytest` nor `nibabel`; no package was installed to
  alter it.
- WSL unit tests, TotalSegmentator installation, model downloads, real
  inference, Slicer-native tests, result import/display, and MRB scene
  persistence were not run by this change and must not yet be reported as
  passing.
- No installed Slicer file, Slicer embedded package, WSL environment, model
  cache, original DICOM file, registration, trajectory, robotics code, or ROS
  component was changed. No implementation was reverted.

## 2026-07-23 20:55:56 IST (UTC+05:30) — Visible volume selector made authoritative

### Corrected diagnosis

- The developer clarified that Slicer's visible **Selected volume** already
  showed the real CBCT, while Bridge B still used `SyntheticCBCT`.
- This supersedes the earlier assumption that the user had left the visible
  selector on the test node. It indicates divergence between the
  `qMRMLNodeComboBox` current node and the persisted parameter-node reference
  trusted by the click handler.

### Fixed

- Added an explicit `currentNodeChanged` handler that synchronizes the visible
  selector's exact MRML node ID into the parameter node.
- Made `onRunRoundTrip` read `inputVolumeSelector.currentNode()` directly,
  validate that it is a scalar volume, and synchronize persistence immediately
  before export.
- The **Bridge input** display now reads from the same selector source used by
  the click handler.
- The imported result name is now forced after load to
  `DENTOBOT_RoundTrip_<run-id>`, independent of file-reader naming behavior.

### Verification

- Static Python AST validation passed.
- All 20 Python UI references resolved against the parsed UI.
- A real-CBCT retry is required to verify the runtime fix. No installed Slicer
  file was modified.

## 2026-07-23 20:47:25 IST (UTC+05:30) — Bridge B synthetic round trip passed and source clarified

### Validation evidence

- The developer reports that Bridge B completed after the compressed-I/O fix,
  returned a volume to MRML, and displayed it in the Slicer slice viewer.
- The successful run used `SyntheticCBCT`, confirming the complete
  Slicer-export, Windows/WSL artifact, backend validation, process completion,
  Slicer-import, MRML geometry validation, and returned-node path for a small
  synthetic volume.

### UI correction

- The run used test data because DENTOWorkflow's persisted **Selected volume**
  still referenced `SyntheticCBCT`; loading another volume does not
  intentionally override an existing explicit selection.
- Added a **Bridge input** field beside the backend configuration. It mirrors
  the exact selected scalar volume that the round-trip button will export.
- Preparation and success status text now name that selected source volume.
  The user must explicitly choose the intended CBCT in the existing Selected
  volume selector before the real-data retry.

### Verification and pending work

- The changed Python passed static AST parsing.
- The UI parsed as valid XML, and all 19 Python UI references resolved.
- A real-CBCT Bridge B run remains pending. No automatic “latest volume”
  override was added because silent source replacement would be unsafe and
  surprising.

## 2026-07-23 20:40:34 IST (UTC+05:30) — Bridge B compressed-NIfTI performance fix

### Observed failure

- The first Slicer-originated Bridge B attempt remained at the backend's
  “Loading input NIfTI” progress event for more than three minutes.
- The implementation calculated a voxel checksum by repeatedly slicing a
  NiBabel proxy backed by compressed `.nii.gz`. On a large CBCT, random slice
  access may repeatedly decompress the same stream and make the checksum
  disproportionately slow.

### Changed

- The Slicer adapter now stages Bridge B input and output as uncompressed
  `.nii` files. NIfTI affine/geometry is retained while avoiding gzip
  random-access overhead across the Windows/WSL boundary.
- The backend now materializes an image proxy once before hashing it in
  bounded planes, so directly supplied compressed NIfTI is processed
  sequentially rather than decompressed for every plane.
- Added explicit input/output checksum progress events, and the Slicer panel
  now displays backend progress messages instead of remaining at “Starting
  WSL backend”.
- Slicer-native tests now clear their synthetic MRML nodes in a `finally`
  block, preventing the test-only `SyntheticCBCT` reference from remaining in
  the Returned volume field after a test run.
- Updated active backend and architecture documentation to show uncompressed
  staging artifacts. Compressed NIfTI remains supported by the backend CLI.

### Verification and pending work

- The changed Slicer and backend files passed static AST parsing.
- The developer must rerun the three WSL tests, reload DENTO Workflow, and
  retry Bridge B. Runtime performance and MRML import are not yet claimed as
  passing.
- The stalled run should be cancelled. No installed Slicer file was modified.

## 2026-07-23 20:31:54 IST (UTC+05:30) — Bridge A translation-name shadowing fix

### Fixed

- Renamed the unused staging-root local in
  `DENTOWorkflowWidget.onCheckBackend` from `_` to `_stagingRoot`.
- Assigning to `_` made it a local variable throughout the method and
  shadowed Slicer's imported translation function `_()`, producing
  `UnboundLocalError` before the WSL health process could start.

### Verification

- The module passed static Python AST parsing after the fix.
- An AST check confirmed that no assignment target named `_` remains in the
  module.
- Slicer-originated Bridge A must be retried after reloading the module. No WSL
  process reached launch during the failed attempt, and no installed Slicer
  file was modified.

## 2026-07-23 20:26:30 IST (UTC+05:30) — Slicer-native tests reported passing

### Validation evidence

- The developer reports that DENTOWorkflow's Slicer-native tests passed inside
  Slicer after the Bridge A/B implementation.
- These tests cover the existing scalar-volume logic plus bridge path mapping,
  argument-list construction, JSON extraction, geometry comparison, and
  parameter-node references without launching WSL.

### Remaining scope

- The WSL configuration values were initially pasted into Bash because the
  prior walkthrough did not state clearly enough that they are labels and
  values for the AI Backend Bridge panel inside DENTO Workflow.
- Bash produced syntax/command-not-found messages only; no environment or
  repository change resulted.
- Slicer-originated WSL health and the complete Bridge B round trip remain
  pending.

## 2026-07-23 20:20:29 IST (UTC+05:30) — Clean WSL backend validation

### Validation evidence

- The developer recreated the Conda environment under the retained name
  `dentobot` and installed the repository as editable with its test extra.
- All three standalone backend tests passed under WSL2 with Python 3.10.20:
  the health-contract test, successful NIfTI data/geometry round trip, and
  missing-input failure result.
- `health --json --require-cuda` returned schema status `ok`, using
  `/home/tarun/miniconda3/envs/dentobot/bin/python`.
- The health result reported one NVIDIA GeForce RTX 4060 Laptop GPU, CUDA
  available, PyTorch 2.10.0+cu130 with CUDA 13.0, NiBabel 5.4.2, and NumPy
  2.2.6.

### Scope and pending verification

- This establishes the standalone WSL backend and CUDA portion of Bridge A.
- The health process has not yet been launched from Slicer. Bridge B has not
  yet exported a Slicer MRML volume, crossed WSL, or imported and validated the
  returned MRML volume.
- TotalSegmentator is intentionally absent from the clean environment at this
  checkpoint and model inference remains unimplemented.
- No source behavior was reverted and no installed Slicer file was modified.

## 2026-07-23 17:05:09 IST (UTC+05:30) — Bridge A/B external inference boundary

### Added

- Added the standalone `Inference/` Python distribution
  `dentobot-inference`, with a minimal Conda environment template and no
  dependency on Slicer's Python.
- Added `health --json --require-cuda`, which reports the actual interpreter,
  core package versions, guarded PyTorch import health, CUDA availability,
  CUDA runtime, and device names without installing or downloading anything.
- Added `roundtrip`, which loads and rewrites a NIfTI image, validates shape,
  affine, voxel type, and a chunked SHA-256 voxel checksum, and always writes a
  schema-versioned JSON result for success or failure.
- Added backend unit tests for the health contract, geometry/data preservation,
  and missing-input failure.
- Added an AI Backend Bridge panel to `DENTOWorkflow` with parameter-bound WSL
  distribution, absolute environment-Python path, staging root, returned
  volume reference, health check, NIfTI round trip, cancellation, status, and
  bounded process output.
- Added a direct asynchronous `wsl.exe` adapter that uses separate arguments,
  a named distribution, and the exact Linux Python interpreter. It does not
  construct a shell command or activate Conda interactively.
- Added isolated run IDs/directories, Windows-to-WSL path conversion,
  NIfTI export, JSON/run-ID/schema validation, MRML import, source/output
  geometry comparison, and `DENTOBOT.*` provenance attributes.
- Extended Slicer-native tests for path conversion, command construction,
  JSON extraction, geometry mismatch rejection, and parameter-node
  persistence. These tests do not launch WSL.

### Changed

- Updated the project context to reflect the developer's existing
  WSL2/Conda/CUDA experience and current focus on Slicer-to-WSL orchestration.
- Updated the active architecture and roadmap to make Bridge A/B the explicit
  gate before TotalSegmentator integration.
- Renamed this file's active title/purpose from DentalNav to DENTOBOT while
  retaining older names in historical entries.

### Verification and limitations

- Static AST parsing passed for the Slicer module and every backend Python
  source/test file.
- The Qt Designer file parsed as valid XML, and all Python `self.ui` references
  resolved to named UI objects.
- Official Slicer 5.12 documentation confirmed that
  `launchConsoleProcess(..., blocking=False)` accepts line and completion
  callbacks with the signatures used by the adapter.
- The ordinary Windows Python available to this coding session lacked NumPy
  and NiBabel. The health command was executed from source and correctly
  returned structured status `error` with exit code 2 and both missing
  dependencies; no package was installed.
- Backend round-trip unit tests were not run because their declared
  dependencies were absent. Slicer, WSL, CUDA, and TotalSegmentator were not
  launched or tested, and no model was downloaded.
- Slicer-native tests, asynchronous callback compatibility, cancellation
  behavior, NIfTI geometry round trip, parameter persistence, and UI layout
  remain to be verified in Slicer 5.12.2 and the user's WSL environment.
- No existing behavior was reverted, no installed Slicer file was modified,
  and TotalSegmentator inference/segmentation import is not yet implemented.

## 2026-07-23 15:49:05 IST (UTC+05:30) — DENTOBOT rename and Step 0 workflow implementation

### Changed

- Renamed the CMake extension project and parent product identity from the
  earlier DentalNav/DentalDrillNav naming to `DENTOBOT`.
- Established `DENTO` plus PascalCase as the identifier convention for all new
  Slicer modules. Examples are `DENTOWorkflow`, `DENTOSegmentation`,
  `DENTORegistration`, and `DENTOTrajectory`.
- Updated the active agent instructions, project context, architecture, and
  development plan to use DENTOBOT naming. Historical entries retain old names
  so the rename remains traceable.
- Removed stale placeholder homepage, icon URL, and screenshot URL values from
  extension metadata instead of replacing them with invented public URLs.
- Changed the root extension build to include `DENTOWorkflow` and exclude the
  legacy `DentalNavPlanning` module.

### Added

- Added the `DENTOWorkflow` scripted module with:
  - a minimal DENTOBOT Step 0 UI;
  - a de-identified case-label field;
  - New Empty Case with explicit confirmation;
  - Open Saved Scene for MRML/MRB scenes;
  - Open DICOM Browser using Slicer's core DICOM module;
  - a parameter-bound scalar-volume selector;
  - automatic display in Slicer's slice views;
  - name, dimensions, spacing, scalar type/range, orientation, and geometry
    status;
  - typed MRML parameter-node persistence;
  - scene-close, module-exit, and cleanup observer handling.
- Added Slicer-native logic tests for missing input, missing image data,
  synthetic volume geometry/metadata, latest-volume selection, and parameter
  node references.
- Added `DENTOWorkflow/CMakeLists.txt` and
  `DENTOWorkflow/Resources/UI/DENTOWorkflow.ui`.

### Preserved or disabled

- The physical workspace directory retains its older name; it is not the
  product identity.
- `DentalNavPlanning` remains in the repository as disabled legacy history.
  Its threshold UI, sample-data behavior, and trajectory experiment are not
  included in the DENTOBOT extension build.
- Original DICOM files remain outside scene clearing and are never modified by
  New Empty Case.

### Verification

- `DENTOWorkflow.py` passed a static Python AST parse. It was not imported or
  executed with system Python.
- `DENTOWorkflow.ui` parsed as well-formed XML.
- All Python `self.ui` references were matched to named objects in the parsed
  UI, and both `SlicerParameterName` bindings were found.
- Root CMake registration was checked to include `DENTOWorkflow` and exclude
  `DentalNavPlanning`.

### Limitations and pending validation

- Slicer was not launched. The module, UI, DICOM browser handoff, MRML
  parameter persistence, scene round-trip, and Slicer-native tests remain
  unverified in Slicer 5.12.2.
- No real or sample DICOM data was loaded.
- No WSL, CUDA, TotalSegmentator, registration, trajectory, or robot behavior
  was added or run.
- No installed Slicer file was read or modified by this change.

## 2026-07-22 20:13:27 IST (UTC+05:30) — Direct WSL process architecture and raw records

### Changed

- Replaced the proposed file/job communication architecture with a directly
  controlled, asynchronous WSL process architecture.
- Defined Slicer as the lifecycle owner: it exports NIfTI, invokes an explicit
  WSL distribution and Linux Python interpreter through `wsl.exe`, streams
  structured stdout, handles cancellation and exit status, validates the
  result, and imports it into MRML.
- Retained an isolated per-run directory only for NIfTI payloads, logs, and
  reproducibility metadata. It is no longer described as a queue, watched
  directory, worker protocol, or process-control mechanism.
- Replaced the planned `segment --request <request.json>` entry point with
  explicit CLI arguments for input, output, device, result JSON, and run ID.
- Reserved persistent HTTP/RPC services for a future measured requirement,
  rather than making one part of the initial design.
- Added mandatory timestamped traceability rules to the agent instructions and
  documented the raw-record layer in project context and architecture.

### Added

- Added `docs/changelog.md` for material repository/specification changes.
- Added `docs/logbook.md` for ideas, prompt/request summaries, decisions,
  experiments, failures, fixes, reversions, and session history.

### Files affected

- `docs/AGENTS.md`
- `docs/PROJECT_CONTEXT.md`
- `docs/ARCHITECTURE.md`
- `docs/DEVELOPMENT_PLAN.md`
- `docs/changelog.md`
- `docs/logbook.md`

### Preserved

- Slicer remains responsible for DICOM, MRML, visualization, interaction, and
  scene persistence.
- PyTorch, CUDA, and TotalSegmentator remain isolated in WSL2.
- NIfTI remains the geometry-preserving bulk image exchange format.
- JSON remains the reproducibility/result metadata format.
- No ROS dependency was introduced.

### Verification and limitations

- This was a documentation-only change. No Slicer, WSL, CUDA, model, or robot
  process was run.
- At `2026-07-22 20:19:48 IST (UTC+05:30)`, all six documentation files were
  checked for stale active-contract phrases and balanced Markdown code fences.
  Historical mentions of the superseded job design were intentionally kept in
  this changelog and the logbook.
- The same check found no non-document file modified after this documentation
  batch began.
- The actual process adapter and backend CLI do not yet exist and therefore
  remain unvalidated implementation plans.
- No application source, installed Slicer file, dependency, or model was
  changed by this update.

## 2026-07-22 19:57:35–19:57:42 IST (UTC+05:30) — Initial architecture and roadmap reset

The timestamps in this heading are derived from the saved file timestamps of
the four governing documents.

### Changed

- Reframed the product as a focused Slicer extension during workflow
  development, followed later by a supported custom Slicer application build.
- Defined Slicer, external inference, and robot-control responsibilities.
- Made a minimal DICOM workflow shell Step 0, ahead of segmentation and
  trajectory planning.
- Isolated inference in a standalone WSL2 package and deferred ROS to a later
  evidence-based robotics decision gate.
- Added explicit protection against editing installed Slicer or original DICOM
  data.

### Superseded detail

- This version proposed a NIfTI/JSON job-directory contract as the primary
  Slicer–WSL interface. The 20:13:27 entry replaced that control model with
  direct process invocation while retaining file artifacts for bulk data and
  provenance.

### Verification

- Documentation structure and code-fence balance were checked.
- No application code was changed in this reset.

## Through 2026-07-22 15:53:04 IST (UTC+05:30) — Retrospective earlier repository state

This entry was written at `2026-07-22 20:13:27 IST (UTC+05:30)` from the
repository and available conversation history. The heading uses the observed
trajectory-file timestamp only to place the reconstructed state in sequence.
The original scaffold-creation time and individual edit times were not
captured, so they must not be inferred from either timestamp.

### Pre-existing scaffold

- `DentalDrillNav` was created using the Slicer Extension Wizard template.
- `DentalNavPlanning` retained the generated threshold UI, sample-data
  registration, threshold logic, and threshold test.

### Exploratory trajectory change

- `DentalNavPlanning/DentalNavPlanning.py` was extended with a
  `trajectoryLine` parameter-node reference, trajectory-line creation logic,
  world-RAS Euclidean length calculation, and Slicer-native test coverage.
- The current file timestamp observed during reconstruction was
  `2026-07-22 15:53:04 IST`.
- The exploratory trajectory code was not removed, but the trajectory-first
  roadmap was superseded by the Step 0 workflow-shell plan.
- A passing in-Slicer result for the final exploratory code is not documented;
  it must therefore be treated as unverified.

### Runtime/dependency state

- No TotalSegmentator, PyTorch, CUDA, or WSL dependency is part of this
  repository at this point.
- Reported failures in the installed Slicer environment did not produce a
  repository dependency change.

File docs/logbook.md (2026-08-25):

# DENTOBOT Development Logbook

## Purpose

This is the raw, append-oriented record of DENTOBOT development sessions. It
captures the reasoning that does not belong in a concise architecture or
roadmap: ideas, user requests and prompt summaries, assumptions, questions,
decisions, attempted implementations, observations, failures, diagnoses,
fixes, reversions, unresolved issues, and next actions.

Every entry must include an explicit date, time, and timezone. One timestamp
may cover a cohesive session update when finer timestamps would be redundant.
If historical material is reconstructed, record the reconstruction time and
state that the original event time is unavailable. Do not record patient
identifiers, credentials, access tokens, or other secrets.

Suggested entry fields are:

- session objective or request summary;
- ideas and alternatives considered;
- decision and rationale;
- implementation or files changed;
- test environment and evidence;
- failure symptoms and likely/confirmed cause;
- fix, reversion, or current disposition;
- unresolved questions and next action.

## 2026-08-25 13:34:00 IST (UTC+05:30) — Step 6.0A required case mouth opening

- Request: require a case mouth-opening step at the start of Step 6 after
  importing the Steps 0–5 package, reusing draft-phantom TMJ hinge logic, then
  continue planning on opened-mouth anatomy.
- Decision: non-destructive derived lower-jaw surface + mandibular display
  proxies; source CBCT/masks untouched; gate 6.1+ until opening is current;
  phantom remains alternate XOR scene.
- Implementation landed in `DENTOWorkflow` UI/parameter node/logic, façade
  `_scene_preparation_issue`, planning-scene/collision consumers, and
  `test_DENTOWorkflowStep6CaseJawOpening`.
- Verification before context-limit interruption:
  `DENTOBOT_CASE_JAW_OPENING_PASS`, focused façade/env tests, host `Testing/`
  suite. Docs completed after the limit recovery. Graphical acceptance after
  reload remains open. Not clinical kinematics.

## 2026-08-25 03:55:00 IST (UTC+05:30) — Connected case save repaired

- Reproduced the reported package audit failure by setting the Step 6 robot
  base's live ROS-active flag and invoking the real package snapshot path.
- The archive audit was correct; programmatic MRB creation had relied only on
  general scene-save observers. It now explicitly makes ROS nodes transient,
  suspends active flags, saves, and restores the running scene's location and
  active flag in `finally` blocks.
- The connected-save smoke verified live-flag restoration, runtime-free package
  reload, and unchanged geometry at `1e-6`, printing
  `DENTOBOT_CONNECTED_CASE_SAVE_PASS`. Its separate historical-package check
  remains unavailable because `dentobot-step6.dentocase` is absent. AST/static
  checks and all 97 host tests passed.
- The active graphical ROS session was not interrupted. Reload the module, then
  retry package save; reconnect explicitly after reload if simulation is still
  needed.

## 2026-08-25 03:18:00 IST (UTC+05:30) — Step 5B representative fusion repaired

- Loaded `test1_5b2.mrb` without saving changes. Its persisted shell and Step 4C
  inputs were stale, so they were regenerated in memory before reproducing the
  reported `[85852, 3, 1, 1]` disconnected occupied-region error.
- All four independent 3.5 mm dock-to-shell branches existed, overlapped each
  endpoint by 2.0 mm, and had only 0.003–0.310 mm shell gaps. The five voxels
  outside the 85,852-voxel main region were numerical islands, not four
  detached docks.
- Final fusion now removes individually microscopic regions only beside one
  printable component, using a resolution-aware 0.1 mm³ bound plus the
  pre-existing one-voxel floor. It records raw and removed-region evidence and
  continues to reject every larger second component.
- The case rebuilt as one watertight occupied volume with four attachment
  records. Focused and complete synthetic Slicer tests, AST parsing, and all 97
  host tests passed. Operator visual/channel inspection and physical validation
  remain open; no MRB, robot, drilling, or patient-facing operation ran.

## 2026-08-25 00:52:52 IST (UTC+05:30) — DENTOWorkflow launch failure fixed

- The launcher parsed successfully, but its first preflight found the host
  Docker service/socket inactive and `/var/run/docker.sock` absent. Starting
  `docker.service` restored Compose; the complete `--check-only` path then
  passed backend health, package builds, render-node checks, and runtime
  safeguards.
- The subsequent full launch exposed a source defect: unconditional
  `docker exec -it` rejected Cursor's non-terminal stdin. The launcher now
  allocates a pseudo-TTY only when stdin and stdout are terminals; normal
  interactive-terminal behavior and attached lifecycle cleanup are retained.
- The successful session later closed with the pinned SlicerROS2 build's known
  VTK-leak exit code. This exposed that signalling only the top-level
  `ros2 launch` PID orphaned its five ROS/MoveIt children. Those exact
  simulation processes were terminated and verified absent. The launcher now
  starts the stack in a separate process group and performs bounded INT, TERM,
  then KILL cleanup across the group.
- Bash syntax, five focused tests, the bounded process-group probe, and the
  97-test host suite passed. The repaired launch started Slicer/SlicerApp-real
  with DENTOWorkflow selected on CRD `DISPLAY=:20.0`; ROS status reported
  `ready:true`, planning ready, and one joint-state source. No hardware motion,
  Execute, drilling, or patient-facing action ran.
- Host window-title tools were unavailable, so process arguments and the ROS
  readiness status are recorded as runtime evidence; operator visual
  acceptance remains separate.

## 2026-08-24 20:53:23 IST (UTC+05:30) — Native Step 6 implementation

- Implemented the requested placement→Task Home→workspace/review→native
  runtime/task confirmation→approach→drilling-preview stack in the Ubuntu
  SlicerROS2 profile. Persistent intent and transient ROS objects now have an
  explicit save/restore boundary; material input changes invalidate phases.
- Added display-only CBCT context and provisional forehead envelope, the
  uncalibrated `dentobot_drill_tip_provisional` frame, and a selective
  target-contact phase guard. Execute and all hardware behavior remain blocked.
- Verified 95 host tests, Slicer MRB renderer/state round trip, operator-scene
  restore and three-package geometry checks at `1e-6`, strict MoveIt smoke, and
  accepted/rejected phase cases. The first isolated normal-window harness set
  ROS domain before sourcing and collided with domain 73; its five exact
  test-only children were stopped and the test was corrected to set the domain
  after sourcing. See `Workspace/docs/logbook/2026-08-24.md` for full evidence.
- Replaced all changed active and canonical Drive documentation by established
  IDs and verified parent/size metadata. No duplicate or research/runtime data
  was uploaded.

## 2026-08-17 16:06:00 IST (UTC+05:30) — Publication outcome

- Created local commits `28d940f` and `901ee17`. The non-force Git push was
  rejected by the environment reviewer because the named destination
  `https://github.com/ghostarun/DentoBot.git` requires explicit private-source
  egress approval. No bypass was attempted; the branch remains ahead locally.
- Exported committed `HEAD` snapshots to isolate them from unrelated dirty
  workstation edits. Drive then replaced 11 established active/controlled
  Markdown files by existing ID and created exactly one `2026-08-17.md` file
  (`1t9OpsCvyiTBCELkSZ-0X9XulF7iieB8i`) in the established dated-log folder.
  A relist confirmed no duplicate. Phantom STLs, screenshots, runtime data,
  patient data, and credentials were excluded.
- A final container process audit found four retained test-only Slicer trees
  from the two visual captures and two invalid harness commands. Terminated
  only `SlicerApp-real` PIDs `467`, `580`, `1407`, and `1507`; the follow-up
  query returned no Slicer, Xvfb, or open-mouth QA process. No interactive
  process was targeted.
- At 16:18 IST the developer explicitly approved egress to the named GitHub
  repository. The non-force push advanced `codex/ubuntu-migration` from
  `f49f4d9` to `f25bf6f`; `git ls-remote` returned the matching full SHA
  `f25bf6f69ad7138d2233343bf0fc40db8cab6380`.

## 2026-08-17 15:52:00 IST (UTC+05:30) — Open-mouth Step 6 workspace trial

- Clarified that 40 mm is the desired approximate final upper-to-lower central
  incisor gap, not a literal mandible translation. Chose an intentionally
  disposable pure TMJ-axis rotation with four manual landmarks rather than a
  clinical jaw model.
- Loaded checksum-verified BodyParts3D neurocranium, maxilla, and mandible
  assets beside the seven-link robot. Added Step 6 load/open/reset/delete UI,
  the visible gap line, base placement controls, and manual joint-workspace
  coverage. The source assets and three QA screenshots remain untracked local
  data; their provenance/checksums are documented.
- Logic chain: role-tagged RAS/STL nodes are resolved from the external data
  root and reused; four ordered world-RAS points define the TMJ axis/incisor
  pair; Rodrigues axis-angle rotation about the TMJ midpoint is sampled from
  -60° to +60° at 0.05°; Euclidean upper-to-transformed-lower incisor error
  selects the best 40 mm candidate with smaller absolute angle as tie-break;
  only the mandible is parented to that rigid transform and a locked Markups
  line reports the achieved gap.
- Robot logic converts display units to URDF SI units, topologically
  accumulates `parent * origin * joint-motion`, converts translations back to
  Slicer millimetres, and parents seven link poses below one base transform.
  Plane snap Gram-Schmidt-orthonormalizes the normal/in-plane axes while
  preserving origin; fine motions post-multiply local rigid deltas. This keeps
  positive J4 following the tracked negative-base-X direction and makes
  buttons/keys follow the placed base axes. Role attributes, not node names,
  drive persistence and scoped cleanup.
- The already implemented self-clearance aid remains a non-blocking 5 mm
  advisory: transform collision-mesh bounds into base-frame AABBs, skip direct
  parent/child pairs, compute Euclidean box separation from per-axis gaps, and
  warn/color non-adjacent pairs below the threshold. It is not used as a
  skull/mouth collision solver and does not evaluate meshes, swept motion,
  cables, the mount, or patient clearance.
- Host geometry tests and focused Slicer logic/widget/MRB tests passed. A real
  Slicer graphical Xvfb run showed the phantom and robot together and reported
  `DENTOBOT_OPEN_MOUTH_VIEWPORT_PASS 40.001 7 3`. The first capture revealed
  that stage visibility logic hid all new/robot displays; restoring display
  visibility while Step 6 is active fixed the defect and the rerun passed.
- The final gate parsed 34 Python and two UI files, checked eight Markdown
  files, and passed. Two interim widget commands used invalid headless harness
  setup (unregistered module, then a main-window-only selector); the corrected
  registered-module `widgetRepresentation()` command exited 0. Inference tests
  were out of scope and explicitly skipped because no backend interpreter was
  supplied to the close-day gate.
- No controller, ROS motion path, hardware, patient data, clinical anatomy,
  exact collision, registration, IK, or calibrated TCP was involved. A
  physical Intel-session trial with deliberate landmark/base placements is the
  next acceptance step.

## 2026-08-17 15:48:35 IST (UTC+05:30) — Keep virtual CRD, correct host stalls

- The developer retained CRD/Xfce for a private virtual desktop and accepted
  force-stopping it before local same-user login. The responsiveness defect
  was isolated from that expected session handoff.
- Journal accounting proved the GDM Wayland greeter consumed 2d 23h CPU over
  3d wall time. The host also used default swappiness 60 and percentage dirty
  limits on a rotational disk; systemd-oomd was already active and correctly
  monitoring the user service.
- Backed up and configured GDM for Xorg, installed/applied swappiness 10 and
  128 MiB/512 MiB dirty-page limits, and extended the health report. Exact
  policy checks, Bash syntax, and whitespace passed. No concurrent Slicer QA
  process was killed.
- The current graphical session was not restarted. Reboot activation and an
  overnight CRD soak remain necessary before claiming the freeze resolved. No
  secrets, patient data, robot action, Git publication, or Drive sync occurred.

## 2026-08-14 19:18:17 IST (UTC+05:30) — Selected zero/base alignment/J4 reversal

- Absorbed the photographed `25.38/0/62.46/0/1.08/-35.28` degree/mm state into
  the integrated URDF as q=0, shifted finite rotary ranges without changing
  span, aligned link-1's mounting face to RViz XY, and negated J4 while keeping
  its positive 0–75 mm range.
- Seven direct and eight Jazzy-reported tests passed. On isolated ROS domain
  174, all six TF perturbations passed including negative-base-X J4. The manual
  run published six zeros and rendered the expected upright pose, horizontal
  base, burr coordinates, and AABBs before clean shutdown.
- Container `check_urdf`, Python compilation, whitespace, and the repository
  close-day gate passed; the first unsourced host `check_urdf` was unavailable.
- Initial shared-domain TF failures came from the developer's still-open manual
  publisher competing with the test. Only exact test/diagnostic processes were
  stopped; the developer session remains active and must be restarted normally
  to load the new URDF.
- This is draft visualization-coordinate evidence, not physical homing,
  calibration, head-mount, Slicer, IK, controller, or hardware evidence. No Git
  publication or Drive sync occurred.

## 2026-08-14 18:46:30 IST (UTC+05:30) — Draft AABB clearance/workspace aid

- The developer bounded the current robot experiment to free manual movement
  for early reach/flexibility exploration before later Slicer head/mouth and
  TBD forehead-mount work. Exact collision, IK, and control are not requested.
- Added seven transformed collision-mesh AABBs, a default 5 mm advisory across
  15 non-adjacent pairs, green/red RViz markers, and base-frame CAD burr-origin
  coordinates. Warnings never block a joint state.
- Six direct tests passed and Jazzy reported seven tests with no failure. RViz
  had one marker publisher and subscriber, displayed the boxes/status, and shut
  down cleanly. Neutral reports two conservative overlaps: link-3/link-5 and
  link-3/spindle.
- The first runtime launch exposed an overly strict resolved-prefix check for
  valid colcon symlink-installed meshes. URI-component validation corrected it;
  the full rerun passed. No Slicer, robot motion, Git publication, or Drive sync
  occurred.
- A 10 mm parameter override was observed exactly and shut down cleanly. The
  repository close-day gate also passed.

## 2026-08-14 18:19:23 IST (UTC+05:30) — Manual joint articulation before Slicer/IK

- Added a URDF-derived PyQt manual joint-state window, dedicated launch,
  neutral/manual/external joint-source selection, RViz host wrapper, static
  coverage, and an independent runtime TF probe.
- Five direct tests and the Jazzy package build/test passed. Each of the six
  joints preserved upstream frames, moved its child according to its declared
  type, and propagated through the downstream tool chain. RViz loaded neutral
  and articulated configurations without mesh/resource errors; isolated runs
  stopped with no residual description process.
- The repository close-day gate passed 32 Python AST parses, two Qt UI files,
  eight controlled Markdown fence checks, backend dependency consistency, 13
  inference tests, and five platform-contract tests.
- Corrected early strict-shell source order, screenshot quoting, overlapping
  stale launches, and interim installed executable names. Cleanup targeted
  only exact process/artifact instances.
- This proves synthetic forward articulation, not physical direction, scale,
  zeros/limits, calibrated TCP, collision, IK, Slicer integration, controller,
  hardware, or safety. No robot motion, Git publication, or Drive sync ran.

## 2026-08-14 17:07:00 IST (UTC+05:30) — Approved documentation and publication checkpoint

- The developer authorized updating controlled documentation, committing and
  non-force pushing the intended working tree, and synchronizing both existing
  Google Drive documentation mirrors.
- Complete Daily Compass review found only the original placeholders and no
  researcher-entered clinical thresholds, decisions, evidence, or patient
  data. Only the reconciliation date and the current bounded Template V0 plus
  description-only/no-motion phase were updated.
- The updated workbook rendered as ten pages; all ten page images were
  visually inspected without clipping, overlap, broken tables, or missing
  glyphs.
- The repository-wide gate passed Python AST (29 files), Qt UI XML (two
  files), Markdown fence checks (eight files), dependency consistency, 13
  inference tests, and five platform-contract tests. Diff whitespace, modified
  shell syntax, three direct description tests, DOCX ZIP integrity, and
  Compose rendering with the documented explicit environment also passed.
- The first direct Compose render omitted launcher-required variables and
  failed before mutation as designed; the corrected explicit-environment
  render passed without starting a container. Three ignored pytest bytecode
  cache files were removed from the untracked package before staging.
- Publication is documentation/source synchronization only. Robot motion,
  drilling, patient-facing operations, force-pushes, and runtime/research data
  uploads remain outside scope.
- At 17:12 IST, the ten established top-level active Ubuntu Drive files and all
  eight established repository-mirror files were replaced in place. The
  previously absent Daily Compass and active dated logbooks for 2026-08-10
  through 2026-08-14 were uploaded exactly once. Folder readback matched every
  expected title, preserved/new ID, MIME type, and local byte size, with no
  duplicate target title. The new Compass ID is
  `1srRKJrQD_ObXx1slR7UqgcE4slSK3LsB`; the five new dated-log IDs are recorded
  in the Ubuntu 2026-08-14 logbook.

## 2026-08-14 16:50:57 IST (UTC+05:30) — Simulation-only robot description integration

- Located the supplied model at workspace-local `data/ROS/assembly`, verified
  the source URDF tree and binary STL structure/checksums, and preserved the
  originals.
- Implemented `dentobot_description`, a neutral no-command joint-state node,
  TF launch, RViz preset, integrity tests, provenance boundary, and safe colcon
  source link. Added a massless `base_link` only to satisfy KDL root-inertia
  behavior; supplied movable geometry remains unchanged.
- Resolved intermediate axis-tolerance, colcon discovery/ownership, KDL root,
  Docker-client lifecycle, duplicate-node, and repeated-SIGINT issues. Final
  Jazzy build/test and headless joint-state/TF/cleanup verification passed.
- This is synthetic description evidence only. Physical dimensions, joint
  calibration, collision geometry, TCP/docking/RAS frames, adapter/control,
  hardware, and motion remain unresolved. No Slicer, robot, drilling, Git
  publication, or Drive sync occurred.

## 2026-08-14 15:18:25 IST (UTC+05:30) — Remote-workstation stability controls

### Evidence and decision

- Investigated an overnight CRD offline/whole-host lag event. Previous-boot
  evidence showed memory pressure and service timeouts, while the development
  container had about 620 tasks with lingering Slicer/Xvfb work and zombies.
  No OOM kill, GPU reset, thermal event, disk error, or logged Wi-Fi loss was
  found. The accepted containment preserves the reusable container but reaps
  descendants, caps tasks, and favors the desktop during CPU/OOM contention.
- A hard RAM cap was rejected pending a representative CPU-segmentation peak;
  prematurely limiting memory could invalidate real inference.

### Implementation, verification, and unresolved state

- Updated Compose, the Ubuntu launcher, the synthetic Bridge B harness, and
  controlled documentation; added a read-only workstation health command.
- Compose/static checks and non-GUI launcher/backend health passed. The full
  synthetic MRML/NIfTI round trip exited 0. Post-test state was docker-init PID
  1, zero zombies, and no remaining Slicer/Xvfb process.
- A deliberate one-second timeout exited 124 and left no runtime descendants.
  The verified-idle container was stopped afterward and remains launcher-
  managed on demand.
- ShellCheck was unavailable. The GDM Wayland greeter remained near 80% of one
  CPU core; a non-interactive sudo restart attempt failed before changing
  state, so local authenticated restart/recheck and overnight observation are
  pending. No Git/Drive publication or robot/hardware action occurred.

## 2026-08-11 20:09:17 IST (UTC+05:30) — Windows/Linux platform contract

### Investigation and decision

- Traced the actual DENTOWorkflow backend adapter, launcher-only Linux
  configuration, prior manual Windows WSL mode, Compose, dependency profiles,
  and platform tests. The geometry/MRML workflow itself contains no material
  host dependency; launcher configuration and file/process boundaries were the
  portability gap.
- Current upstream SlicerROS2 documentation lists Ubuntu 24.04, Jazzy, and
  source-built Slicer 5.10/5.12 as the tested 1.2 target and publishes a Linux
  CI image. DENTOBOT Steps 0–5 do not require its ROS nodes. The selected
  design uses native Windows Slicer plus WSL2 inference without Docker and
  retains Ubuntu Docker/SlicerROS2 for ROS-integrated work.

### Work and evidence

- Added a platform-neutral helper, Windows configuration example/PowerShell
  launcher, shared environment contract, platform-aware UI, explicit Linux
  adapter/device exports, focused tests, and controlled documentation.
- A root-owned pre-existing bytecode cache blocked the first host compile;
  redirecting bytecode to `/tmp` resolved that non-source issue. The base
  Conda interpreter did not include pytest, so the configured backend Python
  ran the tests.
- The host close-day suite initially died inside OpenVINO native device
  enumeration, while the supported container passed all 18 combined inference
  and platform tests. OpenVINO enumeration was isolated into a bounded child
  probe; the subsequent host close-day gate passed 13 inference and five
  platform tests.
- Python/UI/Bash/static checks, the real-host Linux launcher preflight, the
  Slicer-native bridge contract, and actual module launcher-state resolution
  passed. PowerShell AST and Windows runtime acceptance remain open because no
  PowerShell/Windows host is available. No external synchronization, patient
  data, Slicer GUI, robot, motion, or drilling operation was performed.

## 2026-08-10 15:59:55 IST (UTC+05:30) — Step 5C zoom and plane constraint

### Observation and implementation

- The camera lock restored `ParallelScale` on each modification, preventing
  useful zoom recovery. It now constrains orientation/position only: explicit
  isolation applies the initial ROI fit, while zoom remains available with
  yaw enabled or locked and survives later plane/curve actions.
- The simple plane now has one control point. Its origin is projected onto the
  current Step 5B ROI Z axis and its normal remains ROI `+Z`, with transform
  handles hidden. The ROI MRML reference persists and is re-enforced after
  reload and before cutting; validation rejects any bypassed tilt or lateral
  displacement. Read-only installed Slicer headers confirmed both the ROI
  world-Z getter and the one-point Point-Normal plane contract.

### Evidence and external state

- Added a rotated-ROI synthetic constraint case. Python compilation, UI XML,
  whitespace checks, and the repository static gate passed. Live Slicer zoom,
  placement, persistence, and cutting remain developer acceptance items; no
  runtime was launched.
- No patient data, inference, mesh/STL work, robot action, Git commit/push, or
  Drive sync occurred. Changes remain uncommitted above `c574094`.

## 2026-08-10 15:38:25 IST (UTC+05:30) — MPR correction continuity

### Observation and cause

- The first live review found that correcting Entry or Target after selecting
  an MPR angle abruptly reoriented the view. The implementation reapplied the
  same slider number to transverse axes freshly derived from world `+Z/+Y`;
  the number stayed constant but the clinical plane did not.
- Read-only Slicer 5.10 source inspection confirmed Markups point start/end
  interaction events. An unavailable container `rg` command was retried
  successfully with `grep`; no Slicer process was launched.

### Implementation and evidence

- Freeze `SliceToRAS` during the point drag. At release, project the prior
  plane normal perpendicular to the corrected trajectory and reconstruct the
  closest longitudinal frame. In-view edits retain the exact plane, later
  slider motion is delta-based, and a prior-X fallback handles the parallel
  singularity. Reset still reconstructs deterministic world-reference 0°.
- Added focused in-plane, off-plane, fallback, delta, containment,
  orthonormality, handedness, and invalid-input coverage. Python compilation,
  UI XML, and whitespace checks passed. The repository static gate passed 22
  Python AST files, two UI XML files, and eight Markdown fence checks; backend
  tests were skipped because backend source did not change. Live pointer
  stability and FPS remain developer acceptance items.
- No patient data, inference, geometry generation, Slicer launch, robot or
  drilling action, Git commit/push, or Drive synchronization occurred. The
  correction is uncommitted on top of local commit `c574094`.

## 2026-08-10 14:50:42 IST (UTC+05:30) — Longitudinal trajectory MPR extension

### Request and decision

- The developer requested a native oblique CBCT plane containing the existing
  Entry→Target trajectory, with interactive circumferential rotation and no
  duplicate trajectory or resampled volume. Cross-sectional depth views and
  anatomical safety calculations remain future scope.
- Inspection confirmed reuse of the parameter-node Markups-line reference,
  world-point summary, point observers, authoritative segmentation/source-CBCT
  references, and Slicer's slice/composite pipeline. Installed Slicer 5.10
  source confirmed the `SliceToRAS` column convention and Markups projection
  API.

### Implementation and evidence

- Added stable right-handed frame and longitudinal `SliceToRAS` helpers,
  including the near-parallel reference fallback. Added Step 4A enable,
  `-180°..+180°` rotation, reset, existing-line overlay, automatic valid-point
  updates, source-CBCT background, and rotation-invariant initial fit.
- Coalesced slider/point updates and changed only the native slice matrix.
  Captured and restored slice/FOV, composite layers/linking, and trajectory
  display state on all relevant lifecycle boundaries and around scene save.
- Added focused Slicer-native math tests. Python compilation, UI XML parsing,
  whitespace checks, and the repository close-day static gate passed (22
  Python AST files, two UI files, and eight Markdown fence checks; backend
  tests skipped). Runtime tests and interaction/FPS acceptance remain pending
  because no Slicer launch was authorized.
- A 15:00 IST final rerun after the overlay fallback passed the same checks.
  One harmless first whitespace-check attempt ran above the nested Git root,
  returned exit 129, and was repeated successfully from
  `ros2_ws/src/DentoBot`; it made no file changes.

### Safety and external state

- No patient data, inference, new volume, segmentation/mesh processing, robot,
  motion, drilling, STL export, Git publication, or Drive sync occurred.

## 2026-08-10 14:11:28 IST (UTC+05:30) — ROI-frame Step 5C interaction correction

### Request, diagnosis, and decision

- The developer replaced the fixed-anterior Step 5C isolation specification
  with a Step 5B ROI-aligned turntable: look along ROI `+Y` at zero yaw, show
  ROI `+X` right and `+Z` up, align ROI top/bottom to the viewport, lock every
  camera degree of freedom except yaw, and offer a separate yaw freeze.
- The developer also superseded all user-adjustable Step 4A/5B ROI behavior.
  Inspection found Step 5B explicitly unlocked its ROI and the old camera
  observer repeatedly rewrote orientation while all 2D/3D views remained
  active.

### Implementation and evidence

- Added a one-up 3D isolation workspace with complete preservation/restoration
  of layout, camera, crosshair, and visibility. Isolation no longer creates an
  edit markup or starts placement. Camera constraints are derived from the
  current source-matched Step 5B ROI, coalesced, and changed only when a
  property drifts. Plane orientation stays normal to ROI `+Z`. The isolated
  viewport shows an XYZ axes marker and restores the prior marker/axis-label
  state on exit.
- Added distinct persisted non-yaw/yaw locks and made both workflow ROI roles
  locked, non-selectable from views, and handle-free on creation and refresh.
  Step 5B recomputes axis-aligned bounds before generation while retaining its
  historical role string for MRB compatibility.
- Python compilation, Qt UI XML, whitespace checks, and the repository static
  gate passed. Slicer-native camera-math and ROI-policy regressions were added
  but not executed because no Slicer launch was authorized.

### Remaining acceptance and safety

- Developer-run Slicer acceptance must verify mouse yaw, exact viewport fit,
  both lock modes, full presentation restoration, non-interactive reopened
  ROIs, and FPS improvement. No inference, patient data, ROS, robot, motion,
  drilling, fabrication, Git push, or Drive sync occurred.

## 2026-08-07 17:50:52 IST (UTC+05:30) — Step 4A–5C closed workflow and finalization

### Objective and decisions

- The development batch hardened persisted multi-trajectory Step 4A behavior,
  Step 5B ROI ownership and raw shell generation, cross-step visual lineage,
  scene visibility, and clean deletion. It culminated in moving STL export to
  a new non-destructive Step 5C shell-finalization boundary.
- Step 5C uses built-in Markups and Dynamic Modeler: a capped positive/negative
  Plane Cut for the fast horizontal-height path, and a surface-snapped closed
  Curve Cut with inside/outside selection plus explicit capping/topology
  validation for an uneven margin. The Step 5B raw shell remains unchanged.
- The isolated interaction camera is anterior world-RAS, not a derived dental
  or occlusal frame. No automatic 70–80 percent coverage rule is encoded.
  Representative anatomy and dentist-approved margin/contact definitions are
  required before automation.

### Work and evidence

- Updated the DENTO Workflow source/UI, built-in module dependencies,
  parameter-node persistence, role/reference provenance, stale detection,
  lineage display, safe subtree deletion, Step 5B-to-5C cascade, MRB
  lifecycle, and export gating.
- Python compilation, Qt UI XML, and whitespace checks passed. Focused
  synthetic Plane Cut, Curve Cut, Step 5B/5C lifecycle, UI, view, lineage,
  legacy-scene, and clean-deletion checks passed. The correctly registered
  complete Slicer-native suite reached `DENTOWORKFLOW_FULL_SUITE_PASSED`; the
  source build reported known VTK debug leaks after that marker.
- A shortest-distance curve experiment left nine open/non-manifold edges on a
  synthetic sphere and was replaced with the verified cardinal-spline plus
  Dynamic-Modeler nearest-surface path. A separate first full-suite invocation
  lacked the additional module path; rerunning with DENTO Workflow registered
  passed. Neither failure represented retained output or a source regression.

### Publication

- The authorized accumulated batch was committed as `56eaf34` and pushed
  without force to the existing `codex/ubuntu-migration` branch. The first
  restricted-network attempt failed DNS resolution; the approved retry
  advanced the remote from `d08ae89` to `56eaf34`.
- Thirteen existing Google Drive Markdown files across the independent active-
  Ubuntu and canonical mirrors were replaced at their established IDs. After
  confirming the dated-log folder had no 2026-08-07 entry, that one new log was
  uploaded exactly once as `14G3ggC4Ub37jcaocV3T5Ds8Yugrd3CK4`.
- Readback matched the expected ID, name, Markdown MIME type, and exact local
  byte size for all 14 synchronized files (`DRIVE_READBACK_FAILURES=0`).

### Safety and next action

- No patient data, inference, ROS, robot, motion, drilling, or fabrication
  operation ran. Temporary synthetic STL output was deleted by its test.
- Live dentist/developer acceptance remains required for contact, removability,
  cervical/gingival margin, dental orientation, sleeve fit, and printability.
  Arbitrary expert Dynamic Modeler output is not silently adopted by the
  DENTOBOT export gate.

## 2026-08-06 19:21:52 IST (UTC+05:30) — Portable runtime configuration and Git-tracked workspace
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

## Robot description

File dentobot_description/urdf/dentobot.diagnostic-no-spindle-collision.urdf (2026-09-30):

<?xml version='1.0' encoding='utf-8'?>
<robot name="dentobot">
    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
    <link name="base_link" />
    <link name="link-1">
        <inertial>
            <origin xyz="-0.013041482178924977 0.006901703795223388 0.0" rpy="0.0 0.0 0.0" />
            <mass value="0.2395161677577307" />
            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
        </inertial>
        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
    </link>
    <link name="link-2">
        <inertial>
            <origin xyz="1.2434497875801754e-16 -6.217248937900877e-17 0.03821428571428576" rpy="0.0 -0.0 0.0" />
            <mass value="0.2589457744721385" />
            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
        </inertial>
        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
    </link>
    <link name="link-3">
        <inertial>
            <origin xyz="-0.018435581607396664 -0.06961656589240392 -0.036709293065027536" rpy="6.842277657836021e-49 -6.842277657836022e-49 0.0" />
            <mass value="0.4649018982845158" />
            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
        </inertial>
        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
    </link>
    <link name="link-4">
        <inertial>
            <origin xyz="-0.031927753465877604 -6.8567374000849666e-15 -0.01603427299348781" rpy="0.0 -0.0 0.0" />
            <mass value="0.24353233551546366" />
            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
        </inertial>
        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
    </link>
    <link name="link-5">
        <inertial>
            <origin xyz="0.018953104625831423 5.790923296444817e-15 -0.009518341925041305" rpy="0.0 -3.0814879110195774e-33 8.552847072295026e-50" />
            <mass value="0.12052441013845744" />
            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
        </inertial>
        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
    </link>
    <link name="pneumatic_spindle-Copy">
        <inertial>
            <origin xyz="0.021712572259351567 0.006446017878089912 0.03453740536453646" rpy="0.0 -0.0 0.0" />
            <mass value="0.023393660425798164" />
            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
        </inertial>
        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
    </link>
    <link name="burr">
        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
        <inertial>
            <origin xyz="0.0014163069015514563 0.001513483224059975 -0.002820185245171638" rpy="0.0 -0.0 0.0" />
            <mass value="0.0001726305163147505" />
            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
        </inertial>
        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
    </link>
    <joint name="base_link_to_link-1" type="fixed">
        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
        <origin xyz="0.0 0.0 0.0" rpy="-1.5707963267948966 0.0 0.0" />
        <parent link="base_link" />
        <child link="link-1" />
    </joint>
    <joint name="link-1_Revolute-1" type="revolute">
        <origin xyz="0.0 0.0 0.0" rpy="1.570796326794897 -0.4429645641561608 2.90490637318374e-17" />
        <parent link="link-1" />
        <child link="link-2" />
        <axis xyz="0.0 0.0 1.0" />
        <limit lower="-0.44296456415616081" upper="5.8402204358438388" effort="1000000" velocity="1000000" />
    </joint>
    <joint name="link-2_Slider-2" type="prismatic">
        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
        <origin xyz="0.0 0.0 0.0" rpy="-1.5707963267948966 -0.0 1.5707963267948966" />
        <parent link="link-2" />
        <child link="link-3" />
        <axis xyz="0.0 -0.9999999999999999 0.0" />
        <limit lower="0.0" upper="0.08" effort="1000000" velocity="1000000" />
    </joint>
    <joint name="link-3_Revolute-3" type="revolute">
        <origin xyz="-0.047122859999999996 -0.11 -0.09383196" rpy="2.067357736975897 1.101119703255167 -2.067357736975897" />
        <parent link="link-3" />
        <child link="link-4" />
        <axis xyz="0.8936380000000003 -5.639648652959157e-30 0.44878900000000016" />
        <limit lower="-1.0901326507956584" upper="5.1930523492043417" effort="1000000" velocity="1000000" />
    </joint>
    <joint name="link-4_Slider-4" type="prismatic">
        <origin xyz="-0.06702282999999999 0.0 -0.03365918999999999" rpy="-3.141592653589793 2.7755575615628914e-17 5.551115123125784e-17" />
        <parent link="link-4" />
        <child link="link-5" />
        <axis xyz="-0.893638 -2.4694080114073816e-17 0.44878900000000005" />
        <limit lower="0.0" upper="0.075" effort="1000000" velocity="1000000" />
    </joint>
    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
    <joint name="link-5_Revolute-5" type="continuous">
        <origin xyz="-0.021752659999999997 -0.006762529999999991 0.007295090000000003" rpy="-2.933237124130466 -1.553411074346388 2.925952888262058" />
        <parent link="link-5" />
        <child link="pneumatic_spindle-Copy" />
        <axis xyz="-0.38643099999999997 -0.9016699999999997 0.194068" />
        <limit effort="1000000" velocity="1000000" />
    </joint>
    <joint name="pneumatic_spindle-Copy_to_burr_fixed" type="fixed">
        <origin xyz="0.035401760000000004 0.0029788100000000027 0.04568638" rpy="0.9502765943544816 1.0092142015761 -1.935369066862216" />
        <parent link="pneumatic_spindle-Copy" />
        <child link="burr" />
    </joint>
    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
    <link name="dentobot_tool_tcp" />
    <joint name="burr_to_dentobot_tool_tcp" type="fixed">
        <origin xyz="0.0 0.0 0.0" rpy="-2.61089174 -0.36458195 -0.20627347" />
        <parent link="burr" />
        <child link="dentobot_tool_tcp" />
    </joint>
    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
    <link name="dentobot_drill_tip_provisional" />
    <joint name="dentobot_tool_tcp_to_drill_tip_provisional" type="fixed">
        <origin xyz="0.0 0.0 0.007" rpy="0.0 0.0 0.0" />
        <parent link="dentobot_tool_tcp" />
        <child link="dentobot_drill_tip_provisional" />
    </joint>
    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
    <link name="dentobot_drill_tcp" />
    <joint name="pneumatic_spindle-Copy_to_dentobot_drill_tcp" type="fixed">
        <origin xyz="0.041042122156006 -0.000048165096147 0.042853759920214" rpy="-2.224555444403231 0.842809592516694 -2.582877942399306" />
        <parent link="pneumatic_spindle-Copy" />
        <child link="dentobot_drill_tcp" />
    </joint>
</robot>

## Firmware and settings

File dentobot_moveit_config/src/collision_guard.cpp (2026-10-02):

#include <algorithm>
#include <array>
#include <chrono>
#include <cmath>
#include <cstdint>
#include <iomanip>
#include <limits>
#include <memory>
#include <sstream>
#include <stdexcept>
#include <string>
#include <utility>
#include <vector>

#include <moveit/collision_detection/collision_common.hpp>
#include <moveit/planning_scene_monitor/planning_scene_monitor.hpp>
#include <moveit/robot_model_loader/robot_model_loader.hpp>
#include <moveit/robot_model/joint_model.hpp>
#include <moveit/robot_state/robot_state.hpp>
#include <geometric_shapes/shapes.h>
#include <json/json.h>
#include <rclcpp/rclcpp.hpp>
#include <std_msgs/msg/float64_multi_array.hpp>
#include <std_msgs/msg/string.hpp>

namespace
{
constexpr char STATUS_SCHEMA[] = "dentobot.joint_command_status.v1";
constexpr char TASK_CONFIG_SCHEMA[] = "dentobot.task_guard_config.v3";
constexpr char TASK_COMMAND_SCHEMA[] = "dentobot.task_joint_command.v2";
constexpr char TASK_STATUS_SCHEMA[] = "dentobot.task_joint_status.v2";
constexpr char MANUAL_COMMAND_SCHEMA[] = "dentobot.manual_joint_command.v1";
constexpr char MANUAL_STATUS_SCHEMA[] = "dentobot.manual_joint_status.v1";
constexpr char MANUAL_POLICY_ID[] = "raw_planning_scene_acm_transition_v1";
constexpr double CLEARANCE_COMPARISON_EPSILON_M = 1e-9;
constexpr double SIMULATION_GUIDE_CLEARANCE_M = 0.0001;
constexpr double SIMULATION_GUIDE_CONTACT_MAX_PENETRATION_M = 0.0005;
constexpr double CORRIDOR_ENDPOINT_EPSILON_M = 0.00025;
// Match the Step 6 provisional-TCP/FK acceptance tolerance. Smaller values
// reject harmless KDL/trajectory-parameterization jitter below the 0.3 mm case
// surface resolution; larger reversals remain blocked.
constexpr double CORRIDOR_MONOTONIC_EPSILON_M = 0.00025;

std::string json_escape(const std::string& value)
{
  std::ostringstream output;
  for (const unsigned char character : value)
  {
    switch (character)
    {
      case '\\': output << "\\\\"; break;
      case '"': output << "\\\""; break;
      case '\b': output << "\\b"; break;
      case '\f': output << "\\f"; break;
      case '\n': output << "\\n"; break;
      case '\r': output << "\\r"; break;
      case '\t': output << "\\t"; break;
      default:
        if (character < 0x20)
        {
          output << "\\u" << std::hex << std::setw(4) << std::setfill('0')
                 << static_cast<int>(character) << std::dec;
        }
        else
        {
          output << character;
        }
    }
  }
  return output.str();
}

std::string json_number(double value)
{
  if (!std::isfinite(value))
  {
    return "null";
  }
  std::ostringstream output;
  output << std::setprecision(std::numeric_limits<double>::max_digits10) << value;
  return output.str();
}

std::string json_array(const std::vector<double>& values)
{
  std::ostringstream output;
  output << '[';
  for (std::size_t index = 0; index < values.size(); ++index)
  {
    if (index > 0)
    {
      output << ',';
    }
    output << json_number(values[index]);
  }
  output << ']';
  return output.str();
}

std::string json_size_or_null(const std::size_t value)
{
  return value == 0 ? "null" : std::to_string(value);
}

std::string json_point_or_null(
  const std::array<double, 3>& point, const bool available)
{
  if (!available)
  {
    return "null";
  }
  return "[" + json_number(point[0]) + "," + json_number(point[1]) + "," +
         json_number(point[2]) + "]";
}

bool json_string_field(
  const Json::Value& payload, const std::string& key, std::string& value)
{
  if (!payload.isMember(key) || !payload[key].isString())
  {
    return false;
  }
  value = payload[key].asString();
  return true;
}

bool json_number_field(
  const Json::Value& payload, const std::string& key, double& value)
{
  if (!payload.isMember(key) || !payload[key].isNumeric())
  {
    return false;
  }
  try
  {
    value = payload[key].asDouble();
  }
  catch (const std::exception&)
  {
    return false;
  }
  return std::isfinite(value);
}

bool json_integer_field(
  const Json::Value& payload, const std::string& key, std::int64_t& value)
{
  if (!payload.isMember(key) ||
      (!payload[key].isInt64() && !payload[key].isUInt64()))
  {
    return false;
  }
  try
  {
    value = payload[key].asInt64();
  }
  catch (const std::exception&)
  {
    return false;
  }
  return true;
}

bool json_number_array_field(
  const Json::Value& payload, const std::string& key, std::vector<double>& values)
{
  if (!payload.isMember(key) || !payload[key].isArray())
  {
    return false;
  }
  values.clear();
  for (const auto& item : payload[key])
  {
    if (!item.isNumeric())
    {
      return false;
    }
    try
    {
      const double value = item.asDouble();
      if (!std::isfinite(value))
      {
        return false;
      }
      values.push_back(value);
    }
    catch (const std::exception&)
    {
      return false;
    }
  }
  return true;
}

bool json_string_array_field(
  const Json::Value& payload, const std::string& key, std::vector<std::string>& values)
{
  if (!payload.isMember(key) || !payload[key].isArray())
  {
    return false;
  }
  values.clear();
  for (const auto& item : payload[key])
  {
    if (!item.isString())
    {
      return false;
    }
    values.push_back(item.asString());
  }
  return true;
}

bool parse_json_object(
  const std::string& payload, Json::Value& document, std::string& reason)
{
  Json::CharReaderBuilder builder;
  builder["collectComments"] = false;
  std::unique_ptr<Json::CharReader> reader(builder.newCharReader());
  std::string errors;
  if (!reader->parse(
        payload.data(), payload.data() + payload.size(), &document, &errors))
  {
    reason = "Malformed JSON: " + errors;
    return false;
  }
  if (!document.isObject())
  {
    reason = "Payload must be a JSON object.";
    return false;
  }
  return true;
}

struct ManualJointCommand
{
  std::string request_id;
  std::string session_id;
  std::string policy_id;
  std::string operation;
  std::vector<double> joint_positions;
};

bool parse_manual_joint_command(
  const std::string& payload, ManualJointCommand& command, std::string& reason)
{
  Json::Value document;
  if (!parse_json_object(payload, document, reason))
  {
    reason = "Malformed manual joint command: " + reason;
    return false;
  }

  // Keep usable identity for a rejection status even when another field fails.
  json_string_field(document, "request_id", command.request_id);
  json_string_field(document, "session_id", command.session_id);
  json_string_field(document, "policy_id", command.policy_id);
  const bool operation_valid =
    json_string_field(document, "operation", command.operation) &&
    (command.operation == "jog" || command.operation == "state_query");
  const auto malformed = [&reason](const std::string& field) {
    reason = "Malformed or unsupported manual joint command field: " + field + ".";
    return false;
  };
  std::string schema;
  std::string mode;
  std::string policy_id;
  const bool schema_valid =
    json_string_field(document, "schema", schema) && schema == MANUAL_COMMAND_SCHEMA;
  const bool mode_valid =
    json_string_field(document, "mode", mode) && mode == "simulation_only";
  const bool request_id_valid = !command.request_id.empty();
  const bool session_id_valid = !command.session_id.empty();
  const bool policy_valid =
    json_string_field(document, "policy_id", policy_id) && policy_id == MANUAL_POLICY_ID;
  const bool positions_valid =
    json_number_array_field(document, "joint_positions", command.joint_positions) &&
    command.joint_positions.size() == 5;
  if (!schema_valid)
  {
    return malformed("schema");
  }
  if (!mode_valid)
  {
    return malformed("mode");
  }
  if (!request_id_valid)
  {
    return malformed("request_id");
  }
  if (!session_id_valid)
  {
    return malformed("session_id");
  }
  if (!operation_valid)
  {
    return malformed("operation");
  }
  if (!policy_valid)
  {
    return malformed("policy_id");
  }
  if (!positions_valid)
  {
    return malformed("joint_positions (expected five finite ordered J1-J5 values)");
  }
  return true;
}

struct TaskGuardConfig
{
  bool valid{ false };
  std::string task_fingerprint;
  std::string guard_session_id;
  std::string collision_scene_policy_fingerprint;
  std::string target_object_id;
  std::string allowed_robot_link;
  std::vector<std::string> clearance_exempt_object_ids;
  std::vector<std::string> simulation_guide_clearance_object_ids;
  // Per-task opt-in (GUI advanced option) for the 0.5 mm spindle/guide tolerance.
  bool allow_spindle_guide_contact{ false };
  std::string tool_tip_frame;
  Eigen::Vector3d entry_base_m{ Eigen::Vector3d::Zero() };
  Eigen::Vector3d target_base_m{ Eigen::Vector3d::Zero() };
  double corridor_radius_m{ 0.0 };
  double approach_standoff_m{ 0.0 };
  std::vector<double> preflight_start_positions;
};

struct TaskJointCommand
{
  std::string task_fingerprint;
  std::string guard_session_id;
  std::string request_id;
  std::string validation_kind{ "transition" };
  std::string phase;
  std::int64_t sequence{ -1 };
  std::vector<double> joint_positions;
  bool validate_only{ false };
};

struct WorldObjectEvidence
{
  std::string id;
  std::size_t shape_count{ 0 };
  std::array<double, 7> pose_xyzw{ { 0.0, 0.0, 0.0, 0.0, 0.0, 0.0, 1.0 } };
  std::array<double, 6> bounds_m{ {
    std::numeric_limits<double>::infinity(),
    -std::numeric_limits<double>::infinity(),
    std::numeric_limits<double>::infinity(),
    -std::numeric_limits<double>::infinity(),
    std::numeric_limits<double>::infinity(),
    -std::numeric_limits<double>::infinity()
  } };
  bool has_mesh_bounds{ false };
};

struct GuardResult
{
  bool accepted{ false };
  std::string reason;
  std::vector<double> starting_positions;
  std::vector<double> evaluated_positions;
  std::size_t evaluated_sample_index{ 0 };
  double evaluated_interpolation_fraction{ std::numeric_limits<double>::quiet_NaN() };
  std::size_t total_sample_count{ 0 };
  std::size_t checked_samples{ 0 };
  double minimum_self_distance_m{ std::numeric_limits<double>::infinity() };
  double minimum_world_distance_m{ std::numeric_limits<double>::infinity() };
  std::string first_body;
  std::string second_body;
  std::array<double, 3> nearest_point_first_base_m{ { 0.0, 0.0, 0.0 } };
  std::array<double, 3> nearest_point_second_base_m{ { 0.0, 0.0, 0.0 } };
  bool nearest_points_available{ false };
  std::size_t world_object_count{ 0 };
  std::vector<WorldObjectEvidence> world_objects;
  bool corridor_ok{ false };
  double corridor_progress{ std::numeric_limits<double>::quiet_NaN() };
  double corridor_distance_m{ std::numeric_limits<double>::quiet_NaN() };
  bool exploratory_tool_contact_suppressed{ false };
  std::size_t suppressed_tool_contact_sample_count{ 0 };
  bool guide_clearance_warning{ false };
  std::size_t guide_clearance_warning_sample_count{ 0 };
  double minimum_guide_clearance_warning_m{ std::numeric_limits<double>::quiet_NaN() };
  std::string guide_clearance_warning_robot_link;
  std::string guide_clearance_warning_object_id;
  std::string guide_warning_kind;
  double guide_clearance_warning_contact_penetration_m{
    std::numeric_limits<double>::quiet_NaN() };
  std::size_t guide_clearance_warning_contact_sample_count{ 0 };
  std::array<double, 3> guide_clearance_warning_contact_position_base_m{
    { 0.0, 0.0, 0.0 } };
  bool guide_clearance_warning_contact_position_available{ false };
};
}  // namespace

class DentobotCollisionGuard : public rclcpp::Node
{
public:
  DentobotCollisionGuard()
    : Node("dentobot_collision_guard")
  {
    group_name_ = declare_parameter<std::string>("group_name", "dentobot_arm");
    raw_command_topic_ = declare_parameter<std::string>(
      "raw_command_topic", "/dentobot/slicer_joint_positions");
    accepted_command_topic_ = declare_parameter<std::string>(
      "accepted_command_topic", "/dentobot/validated_joint_positions");
    status_topic_ = declare_parameter<std::string>(
      "status_topic", "/dentobot/joint_command_status");
    task_config_topic_ = declare_parameter<std::string>(
      "task_config_topic", "/dentobot/task_guard_config");
    task_command_topic_ = declare_parameter<std::string>(
      "task_command_topic", "/dentobot/task_joint_command");
    task_status_topic_ = declare_parameter<std::string>(
      "task_status_topic", "/dentobot/task_joint_status");
    manual_command_topic_ = declare_parameter<std::string>(
      "manual_command_topic", "/dentobot/manual_joint_command");
    manual_status_topic_ = declare_parameter<std::string>(
      "manual_status_topic", "/dentobot/manual_joint_status");
    minimum_clearance_m_ = declare_parameter<double>("minimum_clearance_m", 0.001);
    maximum_revolute_step_rad_ = declare_parameter<double>(
      "maximum_revolute_step_rad", 0.017453292519943295);
    maximum_prismatic_step_m_ = declare_parameter<double>(
      "maximum_prismatic_step_m", 0.0005);
    maximum_interpolation_samples_ = declare_parameter<int>(
      "maximum_interpolation_samples", 1000);
    // Optional legacy tolerance: accept spindle-housing contact with a configured
    // guide up to SIMULATION_GUIDE_CONTACT_MAX_PENETRATION_M (0.5 mm) as a
    // warning. Disabled by default (operator policy 2026-10-02): the spindle may
    // not touch the template, and drilling is truncated before such contact.
    allow_spindle_guide_contact_ = declare_parameter<bool>(
      "allow_spindle_guide_contact", false);

    if (group_name_.empty() || raw_command_topic_.empty() ||
        accepted_command_topic_.empty() || status_topic_.empty() ||
        task_config_topic_.empty() || task_command_topic_.empty() ||
        task_status_topic_.empty() || manual_command_topic_.empty() ||
        manual_status_topic_.empty())
    {
      throw std::invalid_argument("collision-guard names and topics must be non-empty");
    }
    if (!std::isfinite(minimum_clearance_m_) || minimum_clearance_m_ < 0.0 ||
        !std::isfinite(maximum_revolute_step_rad_) || maximum_revolute_step_rad_ <= 0.0 ||
        !std::isfinite(maximum_prismatic_step_m_) || maximum_prismatic_step_m_ <= 0.0 ||
        maximum_interpolation_samples_ < 1)
    {
      throw std::invalid_argument("collision-guard distances and interpolation limits are invalid");
    }
  }

  void initialize()
  {
    auto robot_model_loader = std::make_shared<robot_model_loader::RobotModelLoader>(
      shared_from_this(), "robot_description", false);
    planning_scene_monitor_ = std::make_shared<planning_scene_monitor::PlanningSceneMonitor>(
      shared_from_this(), robot_model_loader, "dentobot_collision_guard_scene");
    if (!planning_scene_monitor_->getPlanningScene() ||
        !planning_scene_monitor_->getRobotModel())
    {
      throw std::runtime_error("MoveIt could not construct the DENTOBOT planning scene");
    }
    robot_model_ = planning_scene_monitor_->getRobotModel();
    joint_model_group_ = robot_model_->getJointModelGroup(group_name_);
    if (joint_model_group_ == nullptr)
    {
      throw std::runtime_error("MoveIt group does not exist: " + group_name_);
    }
    joint_names_ = joint_model_group_->getVariableNames();
    if (joint_names_.empty())
    {
      throw std::runtime_error("MoveIt group has no commandable joint variables");
    }
    moveit::core::RobotState initial_state(robot_model_);
    initial_state.setToDefaultValues();
    initial_state.copyJointGroupPositions(joint_model_group_, last_accepted_positions_);

    accepted_publisher_ = create_publisher<std_msgs::msg::Float64MultiArray>(
      accepted_command_topic_, 10);
    status_publisher_ = create_publisher<std_msgs::msg::String>(status_topic_, 10);
    task_status_publisher_ = create_publisher<std_msgs::msg::String>(
      task_status_topic_, 10);
    manual_status_publisher_ = create_publisher<std_msgs::msg::String>(
      manual_status_topic_, 10);
    command_subscription_ = create_subscription<std_msgs::msg::Float64MultiArray>(
      raw_command_topic_, 10,
      std::bind(&DentobotCollisionGuard::on_command, this, std::placeholders::_1));
    task_config_subscription_ = create_subscription<std_msgs::msg::String>(
      task_config_topic_, 10,
      std::bind(&DentobotCollisionGuard::on_task_config, this, std::placeholders::_1));
    task_command_subscription_ = create_subscription<std_msgs::msg::String>(
      task_command_topic_, 10,
      std::bind(&DentobotCollisionGuard::on_task_command, this, std::placeholders::_1));
    manual_command_subscription_ = create_subscription<std_msgs::msg::String>(
      manual_command_topic_, 10,
      std::bind(&DentobotCollisionGuard::on_manual_command, this, std::placeholders::_1));
    heartbeat_timer_ = create_wall_timer(
      std::chrono::milliseconds(500),
      std::bind(&DentobotCollisionGuard::publish_last_status, this));

    // PlanningSceneMonitor advertises its own maintained-scene publisher during
    // construction. The guard is read-only: move_group is the sole authority.
    planning_scene_monitor_->stopPublishingPlanningScene();
    // Slicer publishes CollisionObject messages directly. Monitoring that
    // authoritative input avoids a second copy/feedback path through
    // move_group's monitored_planning_scene topic.
    planning_scene_monitor_->startWorldGeometryMonitor(
      planning_scene_monitor::PlanningSceneMonitor::DEFAULT_COLLISION_OBJECT_TOPIC,
      planning_scene_monitor::PlanningSceneMonitor::DEFAULT_PLANNING_SCENE_WORLD_TOPIC,
      false);
    planning_scene_monitor_->startStateMonitor("/joint_states");

    GuardResult initial_result = validate_motion(
      last_accepted_positions_, last_accepted_positions_);
    if (!initial_result.accepted)
    {
      throw std::runtime_error(
        "The URDF/SRDF default state failed the collision guard: " +
        initial_result.reason);
    }
    initial_result.reason =
      "Initialized after validating the URDF/SRDF default state; subsequent commands are collision gated.";
    last_status_json_ = status_json(
      initial_result, last_accepted_positions_, last_accepted_positions_);
    publish_accepted(last_accepted_positions_);
    publish_last_status();

    RCLCPP_INFO(
      get_logger(),
      "Collision guard ready: group=%s, self/world clearance=%.3f m, "
      "interpolation steps=(%.6f rad, %.6f m). Simulation only.",
      group_name_.c_str(), minimum_clearance_m_, maximum_revolute_step_rad_,
      maximum_prismatic_step_m_);
  }
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
int main(int argc, char** argv)
{
  rclcpp::init(argc, argv);
  try
  {
    auto node = std::make_shared<DentobotCollisionGuard>();
    node->initialize();
    rclcpp::spin(node);
  }
  catch (const std::exception& exception)
  {
    RCLCPP_FATAL(rclcpp::get_logger("dentobot_collision_guard"), "%s", exception.what());
    rclcpp::shutdown();
    return 1;
  }
  rclcpp::shutdown();
  return 0;
}

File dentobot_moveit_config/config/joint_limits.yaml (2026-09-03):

# Conservative research defaults for simulation preview only. These values are
# not actuator specifications and must not be used as hardware safety limits.
joint_limits:
  link-1_Revolute-1:
    has_velocity_limits: true
    max_velocity: 0.5
    has_acceleration_limits: true
    max_acceleration: 1.0
  link-2_Slider-2:
    has_velocity_limits: true
    max_velocity: 0.02
    has_acceleration_limits: true
    max_acceleration: 0.05
  link-3_Revolute-3:
    has_velocity_limits: true
    max_velocity: 0.5
    has_acceleration_limits: true
    max_acceleration: 1.0
  link-4_Slider-4:
    has_velocity_limits: true
    max_velocity: 0.02
    has_acceleration_limits: true
    max_acceleration: 0.05
  link-5_Revolute-5:
    has_velocity_limits: true
    max_velocity: 0.5
    has_acceleration_limits: true
    max_acceleration: 1.0

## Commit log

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2026-08-18 feat(step6): add planning pipeline, mount lock, task limits, and simulated motion
    Extend DENTO Workflow Step 6 into four operator stages tied to upstream case
    artifacts:
    - 6.0 Import planning package: one-click validation that CBCT volume, teeth
    segmentation, trajectory, docking assembly, and printable template are linked
    - 6.1 Move and lock robot base mount: freeze base/plane handles before planning
    - 6.2 Task joint limits: user-defined per-joint min/max (deg or mm), clamped to
    URDF mechanical bounds and applied to Step 6 controls
    - 6.3 Simulated trajectory motion: sample Entry-to-Target line, SciPy position
    IK per waypoint, coarse non-adjacent link AABB self-collision, and subsample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
2026-08-19 fix(step6): run ros2 CLI without Slicer PYTHONHOME
    Connect failed because Slicer's PYTHONHOME makes the system ros2 CLI
    load Slicer stdlib and miss rclpy. Source Jazzy in a sanitized child
    environment and cover that case with container tests.
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2026-08-19 fix(step6): keep /slicer healthy on plan and preview
    Check the sourced ros2 node list on Connect, Plan, and Preview. Accept a
    ROS robot without MRML meshes, push preview joints into Motion Control,
    and skip the SciPy IK test when scipy is absent on the host.
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2026-08-19 fix(step6): force a fresh ros2 node list on Connect
    A 1.5 s cache from the failed half-stack made Connect report that
    robot_state_publisher was running without the Slicer joint publisher
    after both nodes were up. Invalidate the cache on start/stop and pass
    force=True into the Connect ready checks.
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2026-08-31 feat(pressure): ship ΔP change-point detector as a portable Arduino package
    Replace the startup residual DIP/PEAK detector with a local-baseline ΔP
    pipeline, DENTIN-armed step/transient events, and linked P/ΔP/dP/dt plots
    so cutting transitions are visible without treating turbine spin-up as a peak.
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2026-09-01 Revert "Lock spindle and preflight full Step 6 chain"
    This reverts commit 0633214735fe74e1156550a595c3446d8c127c1f.
    [collision_guard.cpp]
2026-09-01 Reapply "Lock spindle and preflight full Step 6 chain"
    This reverts commit ed6469c1e37dac14b3020d6c37d4481122eff181.
    [collision_guard.cpp]
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2026-09-07 fix: pin matching torchvision+cu130 for CUDA inference
    Generic torchvision 0.25.0 beside torch 2.10.0+cu130 breaks
    TotalSegmentator with torchvision::nms missing; require the cu130 wheel.
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2026-09-07 docs: DENTO-NOTE Step 5B UX reset viewing Advanced panel
    Record W5-U-05 for dimension coupling, missing Reset, weak interactive
    viewing, and Advanced chrome that hides a required stage.
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2026-09-07 docs: record Windows lab WSLg+CUDA first-install path
    Capture the PLAT-U-04 trial deltas (WSLg graphics, CUDA compose, bat/distro
    fixes, slicer_ros2_module bind-mount build) and update README/SETUP for GPU lab PCs.
2026-09-07 docs: automate TotalSegmentator lab model-cache install
    Add an idempotent install-lab-model-cache helper for tasks 298/115/113 via the
    Python API, wire it into the lab installer, and replace obsolete CLI -t docs.
2026-09-09 lab: pin lab/2026-09-09 and fix update channel + WSL distro detect
    Read LAB_RELEASE from origin/main during update-lab-release so lab PCs can
    move to a newer lab/* tag without a GHCR rebuild when only source changed.
    Auto-detect the host WSL distro in lab .bat launchers (prefer Ubuntu).
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2026-09-09 feat(step6): checkpoint guarded planning and case workflows
    Checkpoint the current simulation-only Step 6 work: phased collision guarding and diagnostics, bounded tool/guide contact warnings, 1 mm burr model, capped insertion evidence, retraction/Home support, segmentation-run isolation, case lifecycle hardening, assisted pulp endpoint and guide-shell geometry, launch/setup updates, verification routing, and controlled records.\n\nVerification: 106 focused tests passed; 40 changed Python files compiled; UI XML, verification JSON, shell syntax, and git diff checks passed. Full exact-case approach/drilling/retraction/Home acceptance remains open because adjacent FDI21 geometry and monitored-st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
    [burr_simulation_1mm.stl, dentobot.urdf]
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2026-09-17 feat(campaign1): read-only static guard and P3–P5 revalidation harness
    Add preflight start joints, static-only task-guard configuration, and deferred
    scene-ack paths so saved FDI31 endpoints can be revalidated without motion
    handshakes; wire policy fingerprints, collision_guard parsing, batch driver,
    verification matrix entries, and supporting tests/docs.
    [collision_guard.cpp]
2026-09-17 fix(workflow): auto-adopt reviewed segmentation for Case Foundation
    Case Foundation gated on planning refs while review state lived on the
    inspection run; entering stage 3 now commits the reviewed handoff and
    clarifies the status when planning adoption is still pending.
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2026-09-18 feat(workflow): virtual open-mouth articulator Phases 2–5
    Replace legacy TMJ hinge solver with AUTO hinge resolution (segmented
    condyles, arch-inferred fallback, manual override) and persist provenance
    through Case Foundation and .dentocase.
2026-09-18 feat(workflow): make AUTO the default Case Foundation open-mouth path
    Keep manual landmarks as a fallback when AUTO fails or the operator
    explicitly overrides, and record the production GUI contract with
    headless test1_post evidence.
2026-09-18 feat(workflow): add simulation-only virtual forehead and extraoral base seating
    Checkpoint VirtualForeheadPriorV1 before replacing Euler seating with frame-to-frame mount alignment so the current plane-plus-identity-base path can be reverted if the geometric contract fails.
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2026-09-18 feat(workflow): add Step 3B placement mirror and fix same-day regressions
    Host offline robot placement as nested Step 3B with a shared 6.1 mirror on one
    MRML robot/base/forehead, then repair operator-found regressions: 3A layout
    orphaning, robot visibility after propose/lock, full New Empty Case workflow
    reset, and safe Step 4A combo scrolling after the first scroll-guard attempt
    broke the panel. Document failures, fixes, and verification in logbook/2026-09-19.
2026-09-18 fix(workflow): land Cursor debug path through Step 6.5 and record PreEntry stall
    This branch now carries operator-confirmed GUI through 6.5 plus Step 5B inherit/bore and lock-crash fixes. Merge to main after further testing and Goal 1 PreEntry planner completion on dentobot-case-step19-step6.
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2026-10-02 Step 6 session runtime, Diagnose This Base, planner speed-ups and watchdogs
    Checkpoint of the S6-LIVE-01 / S6-P2-03 work verified in run r19
    (simulation only): two complete button-driven cycles passed
    (Plan -> Approach preview -> Prepare Drill -> Drill preview -> Return Home x2).
    - Diagnose This Base (6.3) with per-check table; truncated drilling shown
    as a warning with the not-completed remainder highlighted.
    - Plan Approach evaluates all candidates (stamped development fast mode
    only); Complete chains ranked by drilled depth, then arm motion.
    - Candidate-level truncation skips the duplicate guard re-validation (A);
    guard waits spin ROS every poll and process Qt events at most every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
    [collision_guard.cpp]
2026-10-02 Optional incisor-centred task-space box and barrier opacity controls
    Operator 2026-10-03: the task-space box is an optional view, off by
    default, with a user-adjustable side length; it and the entry (mouth)
    barrier get distinct colour profiles, much lower default opacities and
    opacity controls.
    - 6.3 Planning advanced: "Show task-space box (incisor-centred)" (off),
    side length 10-400 mm (default 200), opacity slider (default 10 %);
    mouth barrier opacity slider (default 12 %, was fixed 35 %).
    - Box: cool-blue cube with edges, centred on the workspace ROI draft
    centre when loaded, else the current opened-incisor midpoint. Display
    only: sampling ROI, MoveIt scene and planning gates are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
2026-10-03 Record render fix overlay, decisions and session commands
    SETUP: render-fix SlicerROS2 overlay (native c8b446e) build, hashes,
    use and rollback. DECISIONS: render fix, handshake retry, item C not
    implemented, task-space box, depth peeling pending. Backlog S6-P2-03 and
    S6-WORKSPACE-PURPOSE annotated; logbook facts. Session commands for the
    r19 attribution probes and the r20 overlay check.
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2026-10-03 Add error-log summary and obstacle mesh probes with tests
    error_log_summary reads Slicer's error-log model (what the status-bar
    icon shows); obstacle_mesh_probe finds which path-preflight obstacle
    makes vtkOBBTree log vtkMath::Jacobi warnings.
2026-10-03 Drop zero-area triangles before path-preflight collision trees
    vtkOBBTree divides by each node's summed triangle area; nodes made only
    of zero-area triangles (segment surfaces carry 4-498 each, r23 probe)
    got NaN axes and logged vtkMath::Jacobi warnings (14 per Find Reachable
    Base). Such triangles have no surface; advisory preflight only.
2026-10-03 Load URDF meshes without Slicer's expected STL coordinate warning
    AddModel(path, RAS) still warns that the STL has no coordinate header
    (5-7 per run). One helper hides VTK warnings only during the load and
    restores the previous setting; a failed load still raises.
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2026-10-03 Add NVIDIA workstation render acceptance and stop needless container recreation
    launch-dentoworkflow.bash --render-probe CASE opens the case in Slicer with
    the frame probe, tees the output and judges it with the new
    Testing/evaluate_render_probe.py (NVIDIA hardware renderer on a real
    display, median render interval <= 17.0 ms). NVIDIA/CUDA launches now
    recreate the container only when its NVIDIA GPU request or graphics
    capability is missing. Matrix check runtime.ubuntu_nvidia_render_acceptance
    and the SETUP procedure describe the workstation run.
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2026-10-03 Print the source checkout, branch and commit at launch
    The launcher summary now names the DentoBot checkout and the SlicerROS2
    source with branch, short commit and uncommitted-change count, so the
    running version is visible at every launch.
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2026-10-03 lab: pin candidate lab/2026-10-03-4 with release and safety notes
    Supersedes lab/2026-10-03-3 with the launcher build guard (rebuild robot
    packages built from another checkout, stop on colcon failure) and main listed
    first in --choose-checkout. Native ece3c42 and GHCR image
    jazzy-moveit-sim-20260909 unchanged. No DENTOWorkflow, planner, native or
    image change. Simulation only; candidate pending operator verdicts,
    Windows/WSLg install and NVIDIA hardware checks. Release contents, safety
    notes and rollback in docs/changelog.md.
2026-10-04 fix: Base edit, Find Reachable Base levels 1-4 and collision redelivery
    - Ghost drag observes TransformModifiedEvent so Accept Base commits the
    dragged pose instead of snapping back.
    - Find Reachable Base: persistent result note, reference IK seed when no
    Task Home is saved, mouth-barrier clearance check (level 1), and
    operator-chosen level 2 (nearest shift/depth/yaw of the current Base),
    level 3 (exhaustive, least movement from the auto placement) and
    level 4 ranking board with viewer preview (display-only when locked).
    - Propose Virtual Forehead + Auto Base runs level 1, then level 2.
    - Collision readback re-sends missing or stale objects (bounded) after
    guard sample loss; succ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
2026-10-05 S6-LIVE-01: MoveIt scene gate, frame audit, paced obstacle sync
    - Scene gate before Plan, P1-P3 checks and Diagnose (row 0): compares
    MoveGroup's world objects with Slicer's audit (ids, base-link bounds
    <= 0.05 mm), re-sends only differing objects one at a time (3 rounds),
    refuses on a persistent mismatch; colour badge in 6.3.
    - Root cause of stale MoveIt/guard objects (FDI31 4 Oct; 1-7 teeth after
    Base changes): MoveIt's /collision_object subscriber keeps 10 messages;
    changed obstacles are now paced (0.25 s + 4 us/point).
    - Testing/step6_frame_audit.py: independent scene derivation, three-way
    FK (URDF/KDL/MoveIt), task/axis residuals, collision-boundary agreement.
    All pass in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
2026-10-05 S6-LIVE-01: acknowledged obstacle sync to MoveGroup via /apply_planning_scene
    Changed obstacles are applied to MoveGroup through the synchronous
    service (topic still feeds the collision guard); pacing only as fallback.
    Experiments: service 6/6 + 3/3 raw matches, frame audits PASS; control
    without it went stale 2/3 while the guard ack still said OK. Slicer
    instance limit added to the verification protocol.
2026-10-05 S6-LIVE-01: coordinate-frame check as a standard Diagnose row and evidence item
    - Diagnose row 6: Slicer KDL vs MoveIt-service TCP pose at Task Home and
    each stage end (<= 0.01 mm / 0.01 deg); always runs; a frame mismatch
    outranks planning verdicts.
    - Evidence package runs the full independent frame audit (A-D) and lists
    it in the case summary; missing data is NOT_RUN, not a failure.
    - Bridge: compute_moveit_tcp_pose_world_ras_mm; third guard late-config
    race form retried safely.
    - Protocol: Slicer instances counted with pgrep -x.
2026-10-05 S6-LIVE-01: close frame-audit gaps (angle artifact, barrier parts)
    - Axis-angle comparisons normalise columns: the 0.002 deg KDL/MoveIt/URDF
    offset was Base-matrix column-norm drift (~4e-10) amplified by acos;
    0.0000000 deg after normalising.
    - Frame audit checks the world->base step for the 3 generated mouth-
    barrier parts: 34/34 objects at 0.000 mm.
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2026-10-06 S6-MULTI-TARGET-01: 5-tooth study harnesses, findings, P0 items, presentation format
    - Testing/step6_multitarget_chain.py: build Step 4B-5C for another target tooth in a
    multi-target case without removing other PreparedBranches (activation-owned target
    selection; docking yaw set before the assembly reference).
    - Testing/step6_branch_config.py: per-branch Step 6 working configuration +
    diagnostics stored in a scene node that survives dentocase save/reopen, with
    apply_branch_config to re-apply them (research/testing only).
    - Results: FDI31 3/3 and FDI42 3/3 (6/6 cycles each, drilling shortened WARNING);
    FDI34 fails at PreEntry (lip slab) after every lever within limits.
    - Backlog: P0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
2026-10-07 S6-AUDIT-D-01, S6-MULTI-JAW-STALE-01, S6-FRAME-SYNC-01: audit fix, opening-invariant branches, handoff
    S6-AUDIT-D-01 (resolved, audit defect): the independent check D and the advisor
    runner read the lower-jaw final template without its TMJ mouth-opening parent
    transform (closed-jaw pose, ~24 mm away). MoveIt's template matches the opened
    template to 1e-5 mm; live FDI34 + FDI14 control agree after the fix. Adds the
    read-only MoveIt scene dump (meshes, ACM, padding) and mesh-level comparison.
    S6-MULTI-JAW-STALE-01 (source + pure; runtime pending): PreparedBranch
    provenance is recorded in the owning-jaw frame and branches bind to the
    opening-independent Case Foundation identity (amends DECISIO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
2026-10-07 S6-MULTI-JAW-STALE-01: auto-connect after Step 6 case-load restore
    Restore the selected valid branch configuration after verified case-load
    finalization, then connect through the shell owner. Keep manual Import and
    Restore connect-free and saved Task Home staged only.
    Validation: 27 focused and 80 existing P0 pure checks passed; required
    matrix scopes reproduce only the two documented baseline failures.
    No Slicer/ROS/MoveIt runtime or operator acceptance claimed.
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2026-10-07 Remove fixed model names from AGENTS.md; model is chosen and confirmed per thread
    Operator direction 2026-10-08: no model name in AGENTS.md. Agent (Codex or
    Claude), model, effort and subagent policy are selected per thread and, for
    A/B handoffs, confirmed by the operator before dispatch.
2026-10-07 Promote A↔B handoff/testing rules and Thread handoff procedure into AGENTS.md
    Operator-approved: hard rules live in AGENTS.md (read at thread start by Codex,
    and by Claude via CLAUDE.md), with no fixed model names per 4fb1251. Thread
    handoff text is copied verbatim from the operator's uncommitted edit on A.
    Logbook and DECISIONS record both changes.
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2026-10-08 PLAT-U-07 Goal 2: accept the run's own ros-log/latest symlink; flush request progress lines
    The first real B run (012930c) passed every case check but its DONE.json was ERROR, and collect refused the
    transfer, because ROS logging creates ros-log/latest -> the run's own container log path. Symlinks that only
    point into the run's own tree (relative without .., or under the run's container path) are now recorded in
    DONE.json (symlinks_not_followed) and never followed or hashed; any other symlink, socket, FIFO or device is
    still an ERROR/refusal. request/cmd_request progress lines are flushed so a background job's output file is
    readable while it runs (the buffered client output hid the run-id a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
2026-10-08 S6-ADVISOR-GUI-01: record per-step durations, block an unapproved stored barrier tuning, state the repaint/cancel limit
    - every uninterruptible sub-step (apply steps, prerequisites, stroke, PreEntry, corridor, each
    Diagnose row) records its duration in candidate.json (timings_sec); the ordered report names the
    longest measured step and says it is measured, not accepted (GUI responsiveness stays
    unaccepted, owner S6-P2-03; no threading or event-pump framework added)
    - a case whose stored lip tuning is not an approved value blocks the search with a readable
    setup issue instead of an exception
    - dialog intro states that the window may stop repainting during one planning step and that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
2026-10-08 S6-ADVISOR-GUI-01: a refused trial sync must not make the restore sync look like missing barrier evidence
    Found in the scoped diff review. The audited-barrier-fingerprint guard compared against the audit
    before the call, so after a refused sync (scene still on the original barrier) the restore of the
    original tuning raised "geometry did not change" and the restore was reported unconfirmed. The guard
    now applies only when the scene was really holding other values (last synced tuning). Regression
    test fails without the change (checked by mutation) and passes with it.
2026-10-08 S6-ADVISOR-GUI-01: consent-gated Task Home revalidation (decision D1 option O4) in the service and dialog
    Tarun approved ("do it", 2026-10-08) that an explicit-consent SIMULATION search may re-validate the unchanged
    saved Task Home joints under each trial configuration through the existing production owners, creating new
    validation revisions. Source/test authority only; no runtime.
    - advisor_home.py (new): HomeRevalidator — only stageManualTaskHomeReview(saved joints) +
    acceptManualTaskHomeReview() create authority (the production accept path itself enforces
    accepted == monitored == displayed == candidate within 1e-12 and the strict collision guard); never writes a
    Home record/flag/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
2026-10-08 S6-ADVISOR-GUI-01: the restore of an opening trial also pauses for the operator's Connect and Continue
    After an opening trial the restore disconnects ROS again and the original joints cannot be re-validated
    without a connection. Instead of ending blocked, the restore now pauses exactly like the trial path (the
    advisor never connects itself); Continue refuses ROS-disconnected, joint drift and identity drift and never
    rebases; the restore then re-validates the same original joints through the production owners.
2026-10-08 S6-ADVISOR-GUI-01: wire-test the Step 6.3 consent, pause, Continue and Cancel GUI paths
    Adds fake-host tests for the default-off Task Home consent checkbox (grant only when checked, exact CONSENT_TEXT before prepare, unchecked after finish and restore-unconfirmed, enabled only while idle), the pause tick (no timer restart), refused and accepted Continue, Cancel, Close and window reject while paused, navigation and non-Connect fixes refused while paused, and button visibility per mode. Widget source is unchanged.
2026-10-08 S6-ADVISOR-GUI-01: dialog fixes from the worker review, probe helpers and session commands for the bounded B verification
    - widget: consent can be ticked before "Keep searching" (done mode); the stale pause label is cleared on resume and on
    cancel-from-pause; consent resets when Start is blocked at setup; Continue is exception-guarded and stays paused
    - Testing/step6_advisor_probe.py (+ tests): invariant snapshots and diffs, OwnerGuard (refuse/count, restores the class
    method), flushed per-line Timeline, session/handler instrumentation and the cancel-latency combiner
    - Testing/step6_session_commands/advisor_{precheck,baseline,consented_trials}.py: commands for the EXISTING persistent
    h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
2026-10-08 S6-ADVISOR-GUI-01: direct unit tests for the Task Home revalidation helper
    Tests advisor_home.py with tiny fakes (no service, Slicer, ROS or MoveIt):
    joint tolerance boundaries and each unreadable joint source, the owner calls
    each refusal makes or must not make, the ledger file and summary text, the
    record helpers, stable_identity, and the OperatorPause file. 65 cases; the
    session test test_advisor_home_revalidation.py is unchanged and still passes
    (21). No source file is modified.
2026-10-08 S6-ADVISOR-GUI-01: fix the Home-helper defects found by the W4 review; merge its unit tests
    W4 (Haiku 5.5 max) added 65 unit cases for advisor_home (27/27 mutations caught) and reported real defects:
    - an unexpected exception after a committed accept left the ledger entry "started" and the revision unrecorded:
    revalidate() now finishes the entry (outcome refused, code unexpected, after-summary read) and never retries
    - a gap-rejected accept left the expected identity behind the production record: the accept was the advisor's own,
    so the identity is adopted (but not when the saved joints changed during acceptance)
    - malformed/non-numeric joint identity is an issue, not an exception; a fai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
2026-10-09 S6-ADVISOR-GUI-01: user-like tab navigation before real-input presses
    A control on a non-current QTabWidget page, including a nested one, is now reached
    with real XTest presses on the tabs, outermost first. Each tab press uses the same
    window activation and X-level hit test as a control press, and is confirmed by
    currentIndex. Each tab press is its own ledger entry (navigation "tab").
    Other hidden or collapsed reasons may use the runner's direct navigation helper
    (shell substep page). Its use is logged as navigation "direct" with the reason, and
    visibility is checked again. A disabled control is refused before any navigation.
    A control that is still not visible fails loudly.
    Host tests cov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
2026-10-09 S6-ADVISOR-GUI-01: press a check box on its indicator; accept clicked arguments
    A QCheckBox is wide and Qt only hit-tests its indicator and label text
    (SE_CheckBoxClickRect). The real press was aimed at the centre of the
    whole row, which is empty space, so a consent click was not delivered.
    A check box or radio button is now pressed on its indicator, at a fixed
    offset from the left edge, and the delivery probe accepts the bool that
    QCheckBox.clicked passes.
    Host test: a wide check box is pressed at its indicator (not the row
    centre) and a bool-argument clicked counts as delivery. The test fails
    on the previous commit.
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
